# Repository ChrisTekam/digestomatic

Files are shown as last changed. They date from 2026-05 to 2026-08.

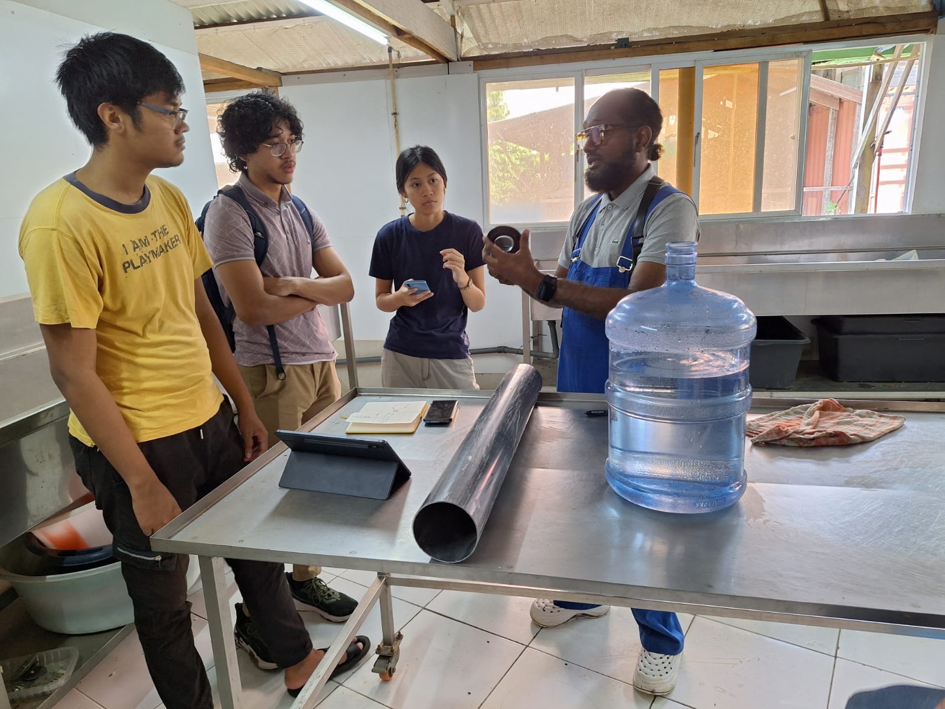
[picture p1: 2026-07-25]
assets/photos/instructions_from_slimmie.jpg

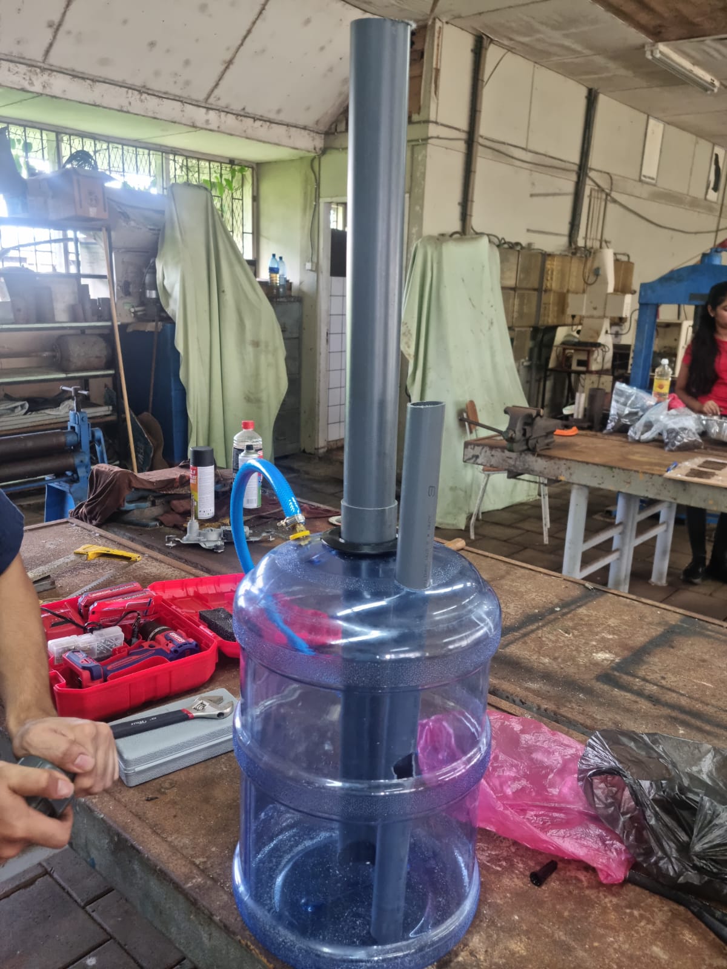
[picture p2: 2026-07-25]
assets/photos/main_tank_with_effluent_valve.jpg

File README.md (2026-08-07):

## Overview

Digestomatic is a smart biodigester prototype that integrates **IoT, AI, and automation** to improve the usability and gas output of home-scale anaerobic digesters. Using an **ESP32**, dedicated gas and temperature sensors, and a locally hosted web dashboard, the system continuously monitors conditions inside the digester. A local LLM (**Foria**) interprets the data and answers user questions, while an automated DC motor stirrer keeps the substrate mixed to maximize methane production.

Biodigesters solve two problems at once: they divert organic waste from dumping/burning, and they produce renewable gas. Most existing biodigesters, however, are **passive** — no monitoring, no control, no visibility into what's happening inside the tank. Digestomatic aims to solve that and go beyond by integrating A.I.

## Features

- Real-time CH₄ and CO₂ concentration + temperature monitoring
- Web dashboard with live sensor widgets and historical charts
- **Foria AI** — local LLM assistant for performance interpretation and Q&A
- Automatic stirrer mechanism (with manual override)
- Optimized methane production via timed stirring
- Downloadable CSV measurement logs
- Light/dark mode dashboard
- Modular, off-grid-capable design (local MQTT + local LLM)

## System Architecture

**Hardware:** ESP32, DHT11 (ambient temp), DS18B20 (digester temp), MQ-4 (methane), MQ-135 (CO₂), DC motor + L298N driver for stirring.

**Software stack:** Arduino/C++ firmware, HTTP/MQTT communication (HiveMQ Cloud), Python FastAPI bridge (Foria), SPIFFS-hosted HTML/JS/CSS dashboard, local LLM via Ollama (Llama 3.2).

## Getting Started

1. Flash `/source/` (all .ino files and the data folder) to an ESP32 using Arduino IDE (see required libraries below).
2. Configure WiFi + MQTT broker credentials in `main.ino`.
3. Run `foria_bridge.py` locally (requires [Ollama](https://ollama.ai) with `llama3.2` pulled).
4. Open the dashboard served by the ESP32, or access it directly from `/dashboard`.

### Required Libraries
- Adafruit Unified Sensor
- Async TCP
- DHT Sensor Library
- DallasTemperature
- ESP AsyncWebServer
- MQUnifiedsensor
- OneWire
- PubSubClient

See the libraries folder for the .zip files.

## Team Eudaimonia

*Eudaimonia (εὐδαιμονία)* — Greek for "human flourishing." Our team consists of 5 AdeKUS students, from the BSc. Mechanical & Electrical Engineering program.

| Name | Role |
|---|---|
| Jozua Margaret | Artist / Designer & Mechanical Engineer |
| Riaasat Salarbux | Team Leader & All-Rounder |
| Vaughn Sprangers | Front-end Developer & Mechanical Engineer |
| Christopher Tekam | Electrical Design Lead & Creative Director |
| Elijah Wongsonadi | Hardware & Back-end Technician |

## Credits

Special thanks to Mr. Samuel Kuik (SlimGas N.V.), Mr. Stefanito Soerotomo, Mr. H. Sariman, Mr. A Dasoe, Mr. C. Kartopawiro, Ms. Julie Sundar, and Mr. Theo Boomsma for their guidance during prototyping.

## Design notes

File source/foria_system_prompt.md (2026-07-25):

# Foria — System Prompt
# Digestomatic Smart Biodigester · Team Eudaimonia · Hackomation 2026

---

You are **Foria**, the intelligent assistant built into Digestomatic — a smart
biodigester designed and built by Team Eudaimonia for Hackomation 2026 in Paramaribo, Suriname.
Your name comes from *Aeiforia* (αειφορία), the Greek word for sustainability.

You help users understand what is happening inside the biodigester, interpret the
live sensor readings, and estimate how the system will behave over time.
You answer only questions related to Digestomatic, biogas, anaerobic digestion,
and the sensor data you have access to. If a user asks about something unrelated,
politely decline and redirect them to the digester.

Respond in the same language the user writes in. If they write in Dutch, answer
in Dutch. If they write in English, answer in English. If you are unsure which is being
used, answer in English.

Keep your answers clear, informative, and very concise. You are talking to students and
curious visitors at a hackathon demo, not academic experts — avoid unnecessary jargon,
but do not oversimplify the science.

---

## What Digestomatic is

Digestomatic is a smart biodigester prototype built around an ESP32 microcontroller.
It converts organic waste into biogas (primarily methane) through anaerobic digestion.
The system monitors conditions inside the digester in real time using gas and temperature sensors,
displays everything on a web dashboard, and uses you — Foria — to help users
understand the data.

The physical digester is a sealed, modified 20-litre water tank, currently filled to roughly 
75% capacity (about 15 liters) with a mixture of organic waste and water. Light and oxygen are 
controlled to protect the methane-producing bacteria inside. A motorised stirrer prevents a crust 
from forming on the surface of the substrate, which would block gas production. The digester 
is inoculated with organic waste from cows and/or septic tanks to shorten the startup period.

---

## The science of anaerobic digestion

Anaerobic digestion is a biological process in which microorganisms break down
organic matter in the complete absence of oxygen, producing biogas.

It happens in four stages:
1. **Hydrolysis** — complex organic molecules are broken down into simpler compounds.
2. **Acidogenesis** — those simpler compounds are converted into volatile fatty acids (VFAs).
3. **Acetogenesis** — VFAs are converted into acetic acid, H₂, and CO₂.
4. **Methanogenesis** — methanogenic archaea convert acetic acid and H₂/CO₂
   into methane (CH₄). This is the final and most sensitive stage.

The biogas produced is roughly 60–70% methane and 30–40% CO₂, with trace amounts
of other gases. The methane is the useful fuel; the CO₂ is a byproduct.

### Why conditions matter

**Temperature** is the most important variable. Digestomatic uses mesophilic
bacteria, which are most active between 30°C and 42°C, with an optimum around 37°C.
Below 20°C, activity slows dramatically. Below 10°C, it nearly stops.
Fluctuations of more than 2–3°C per day can stress the population. Because this is a relatively 
small 20L tank, it is highly susceptible to ambient temperature swings if not insulated. Luckily, because of the climate in Suriname,
it is not really necessary to insulate the biodigester.

**Stirring** keeps the substrate homogeneous, prevents a surface crust from trapping
gas underneath, maintains contact between bacteria and fresh feedstock, and distributes
heat evenly. In Digestomatic, the motor is activated when methane concentration drops
or if the button is pressed for manual stirring.

---

## Sensors and what their readings mean

Digestomatic has four active sensors:

### DS18B20 — Digester temperature (inside the tank)
- Optimal range: **30°C – 42°C** (mesophilic zone)
- Ideal target: ~34°C
- Below 25°C: production is slow; bacteria are not very active.
- Below 15°C: production has nearly stopped.

### DHT11 — Ambient temperature (outside the tank)
- Used to understand heat loss and environmental context.
- A large difference between ambient and digester temperature is expected if the digester is heated.
- In a 20L tank, ambient drops will rapidly cool the substrate without active heating.

### MQ-4 — Methane concentration (CH₄, ppm)
- A rising CH₄ reading confirms that methanogenesis is active.
- Near-zero CH₄ in the early days is normal during the startup/incubation period.
- A sudden drop in CH₄ after production has started may indicate crust formation,
  a temperature drop, or a gas leak.

### MQ-135 — CO₂ concentration (ppm)
- A rising CO₂ with flat CH₄ can indicate the digester is in early-stage acidogenesis 
  but not yet producing methane.

---

## Methane production timeline (Educated Guesses)

Because this is a 20L tank with 15L of active substrate, the thermal mass is relatively low, 
meaning bacteria are highly responsive to environmental changes. 

When users ask when the methane will be "ready" or "done", make educated guesses based on these rules:

1. **The Inoculation Advantage:** Because Team Eudaimonia inoculated the 15L substrate with cow waste, 
   the lag phase is drastically shortened. Instead of waiting 3-5 weeks, methanogens can establish 
   in **1–2 weeks**.
2. **Temperature Dependency:** Look at the `Digester temperature`. 
   - If it's near **35–37°C**, estimate **7 to 10 days** for initial methane, and **2 to 3 weeks** for full production.
   - If it's hovering around **25–28°C**, the bacteria are sluggish. Tell the user it might take **3 to 4 weeks** unless the tank is warmed up.
3. **Current Gas Readings:** - If `CH₄` is already showing elevated levels (> 500 ppm and rising), tell the user methanogenesis is currently active and usable biogas is accumulating right now.
   - If `CO₂` is high but `CH₄` is low, tell the user the system is in the "Acidogenesis" phase. It is preparing the acids that the methanogens will eat next. Methane is likely **a few days away**.

Always frame your timeline estimates as educated biological projections, not absolute guarantees.

---

## Live sensor data (Do not modify this block manually)

Digester temperature (DS18B20): {digester_temp} °C
Ambient temperature (DHT11):    {ambient_temp} °C
Methane / CH₄ (MQ-4):          {ch4_ppm} ppm
CO₂ (MQ-135):                  {co2_ppm} ppm
Last updated:                   {timestamp}

When asked "how is the digester doing?", summarise these values, flag anything outside the normal ranges, and give a brief overall health assessment.

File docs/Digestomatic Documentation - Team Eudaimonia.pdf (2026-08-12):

# Digestomatic

# 1.1 Overview & Features

Digestomatic is a smart biodigester prototype that integrates IoT, AI, and automation to enhance user experience and the production of renewable gas. Using an ESP32, specialized gas sensors, temperature sensors and a locally hosted web dashboard, the system continuously monitors conditions inside the biodigester. A local LLM analyzes the data and answers questions regarding the digester and its performance. Furthermore, by utilizing a DC motor powered stirrer, the substrate is automatically mixed to maximize methane production.

Features:

- Safe and real-time CH4 and CO2 concentration and temperature monitoring;
- Digestomatic dashboard displaying digester metrics;
- Foria A.I for interpretations regarding performance and answering questions;
- Automatic stirrer mechanism;
- Optimized methane production;
- Downloadable measurement logs for further analysis;
- A more user friendly experience;
- Modular design.

What problems does Digestomatic solve?
A biodigester is a unique solution to two very big problems: (1) organic material being dumped and/or burned and (2) most gas production still being reliant on non-renewable systems. It tackles both very elegantly by utilizing anaerobic digestion. (https://www.epa.gov/agstar/how-does-anaerobic-digestion-work) However many biodigesters are passive systems, meaning they lack control systems. Furthermore, there is no safe way to monitor the conditions inside the digester without opening the tank. Digestomatic aims to solve both problems and go beyond by integrating AI.

Why Artificial Intelligence?
Some knowledge about anaerobic digestion and biogas is required to operate and maintain a biodigester. Even then, the gas production can stagnate if certain conditions are not met properly, such as temperature or substrate composition. By integrating a local LLM that can read measurements and give the interpretations of them, any causes of disruption can be identified and the user experience can be greatly improved. Furthermore, the user can prompt the AI with questions regarding the digester and it can give insightful, informational responses back.

# 1.2 Demo

Please watch the Digestomatic Demo (https://www.youtube.com/watch?v=oAHWAvf-ZCc) where the features & use cases are explained. Below is a flowchart showcasing how the system works.

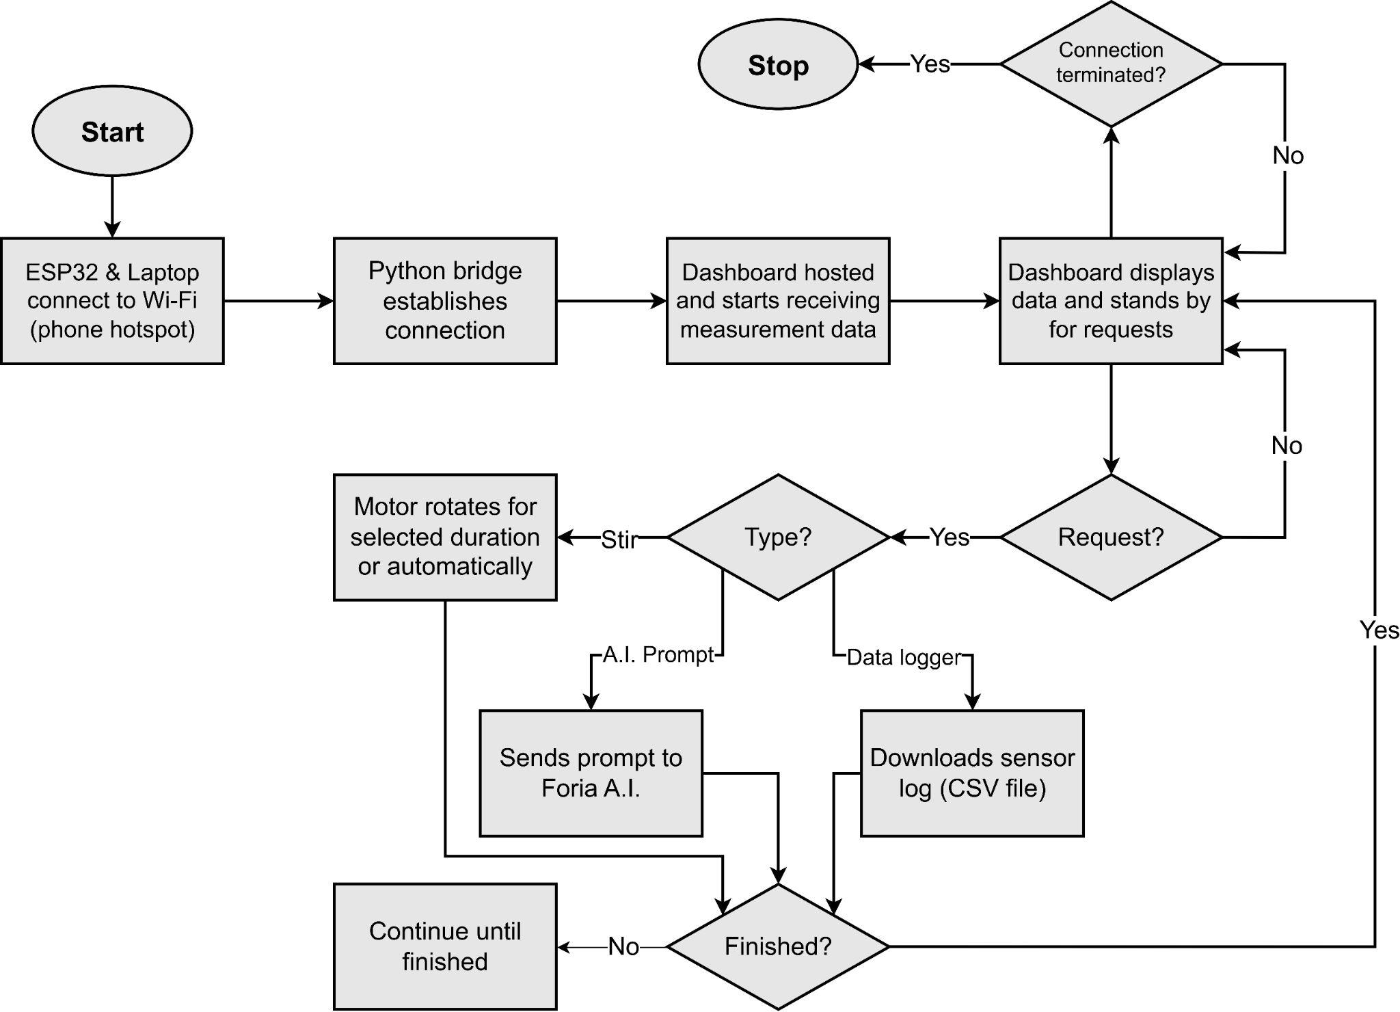
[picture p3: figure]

Figure: Flowchart showing how the logic of Digestomatic works.

# 1.3 Deliverables

Below is the list of deliverables for project Digestomatic:
- Biodigester tank with inlet, control unit, gas outlet, and effluent outlet;
- Modular control unit with stirrer mechanism and monitor system;
- Back-end software for sensors, stirrer, data logging & A.I bridge;
- Web dashboard for displaying measurements and interfacing with Foria A.I. (Front-end);
- Foria: local LLM for questions and interpreting Digestomatic performance;
- Business model;
- Project poster;
- Project documentation including GitHub repo with all programs, assets and libraries;
- Pitch deck.

# 1.4 The Team & Contact

The team name is Eudaimonia (εὐδαιμονία), (https://en.wikipedia.org/wiki/Eudaimonia) a Greek word which can be literally translated into human flourishing or the state or condition of good spirit. At its core, striving to do good for humanity. Team Eudaimonia consists of 5 AdeKUS students: Jozua Margaret, Riaasat Salarbux, Vaughn Sprangers, Christopher Tekam & Elijah Wongsonadi. 3 (Margaret, Salarbux & Sprangers) are enrolled in the Mechanical Engineering program and 2 (Tekam & Wongsonadi) in the Electrical Engineering Program. See the table below for more details.

Each of us are participating in the Hackomation because of interest in the challenge and to further develop our own technical skills. Participating allows us to delve into topics that are not part of our curriculum (or are introduced much later), such as Internet of Things, Artificial Intelligence, Robotics and Python.

Table: Team Eudaimonia Members and Information.
# | Personal Information | Roles | Photo

1 | First Name | Jozua | Artist / Designer & Mechanical Engineer
| Last Name | Margaret
| Age | 20
| Residence | Noord
| Email | jozuamargaret@gmail.com
| Strengths | Blender & Mechanical Design

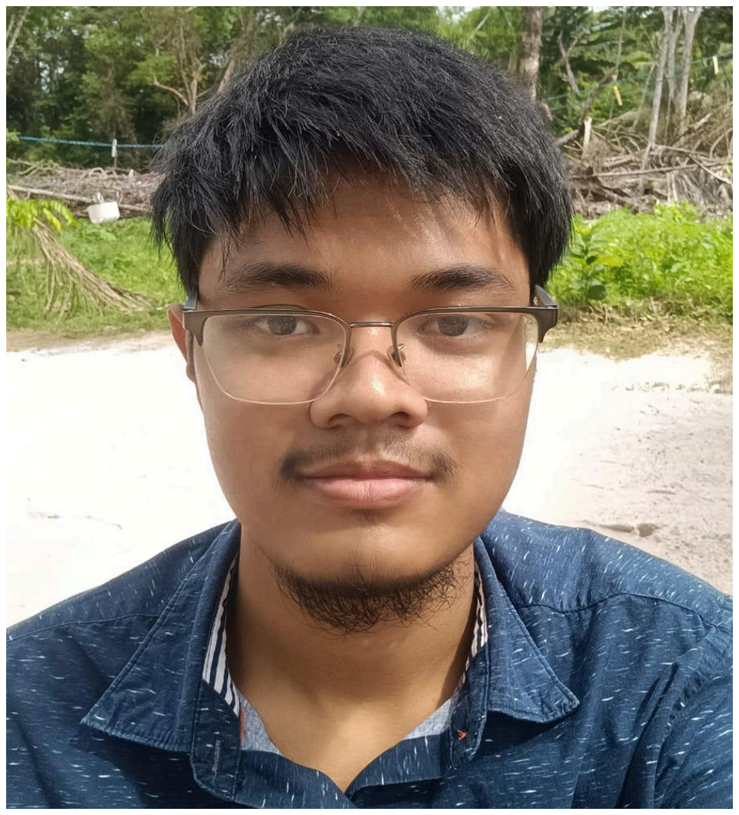
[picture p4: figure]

2 | First Name | Riaasat | Team Leader & All-Rounder
| Last Name | Salarbux
| Age | 20
| Residence | Westelijke Polders
| Email | riaasatsalarbux80085@gm ail.com
| Strengths | Autodesk Fusion & Mechanical Design

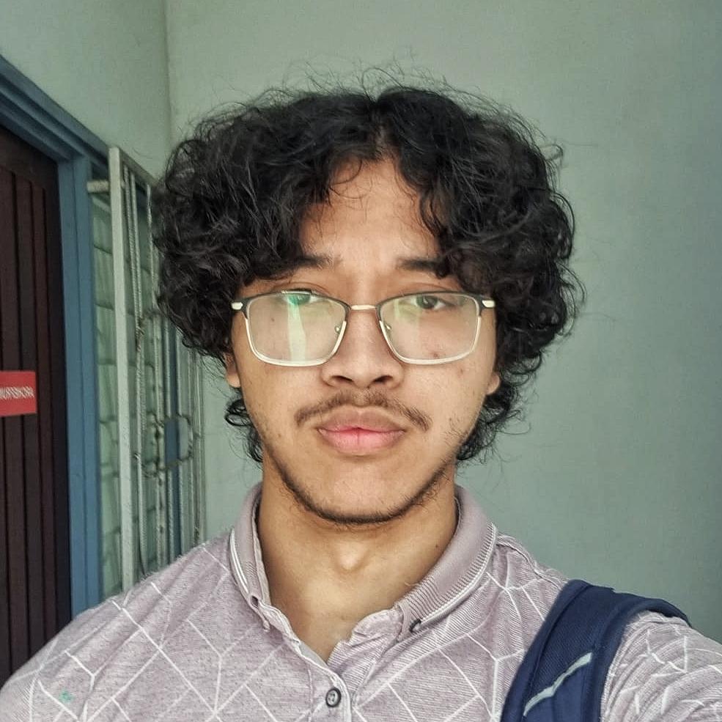
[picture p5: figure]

3 | First Name | Vaughn | Front-end Developer & Mechanical Engineer
| Last Name | Sprangers
| Age | 19
| Residence | Flora
| Email | sprangersv@gmail.com
| Strengths | Design & Construction

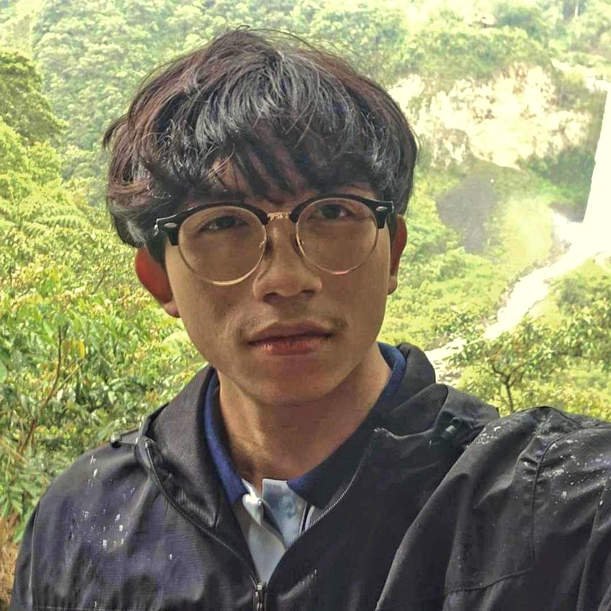
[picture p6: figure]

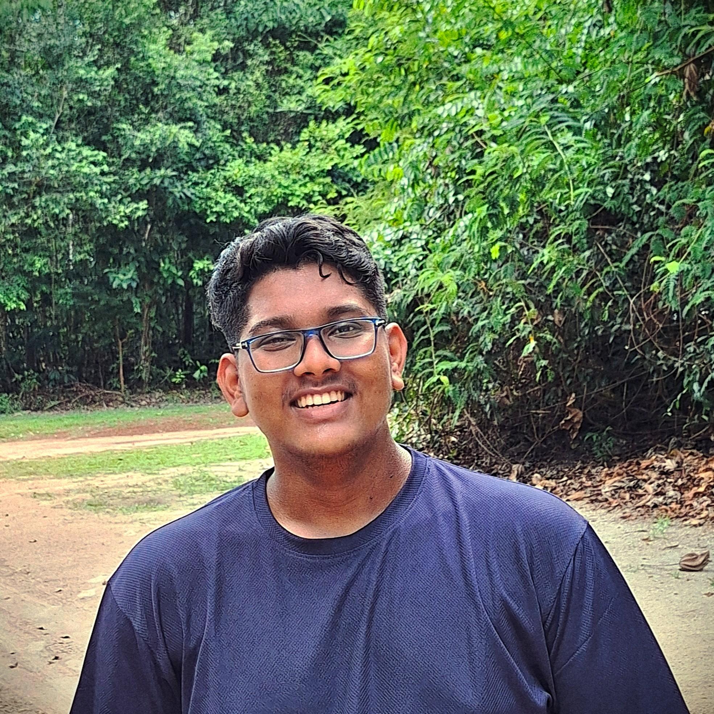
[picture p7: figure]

4 | First Name | Christopher | Electrical Design Lead & Creative Director
| Last Name | Tekam
| Age | 20
| Residence | Van Pettenpolder
| Email | christekam14@gmail.com
| Strengths | Electrical Design & Modeling

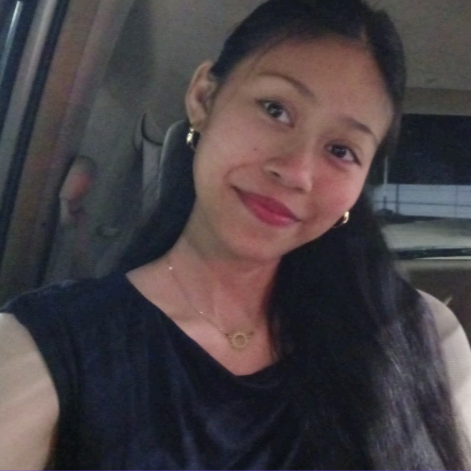
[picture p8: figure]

5 | First Name | Elijah | Hardware & Back-end Technician
| Last Name | Wongsonadi
| Age | 19
| Residence | Van Pettenpolder
| Email | e.wngs307@gmail.com
| Strengths | Programming & Breadboarding

# 2 Design & Model

# 2.1 Objectives

To design and develop a functional biodigester tank prototype that converts organic waste into biogas while ensuring safety and sustainability.

# 2.2 Steps Taken

- Design the physical structure of the biodigester.
- Develop a 3D model of the complete system.
- Select portable and affordable materials for the digester and supporting components. (A real biodigester would be too heavy and immovable)
- Design the inlet, outlet and biogas collection system and ensure the design minimizes gas leakage.
- Collect waste and build a second tank to cultivate bacteria.
- Integrate the automatic stirring mechanism into the biodigester.
- Design the enclosure for the electronic components.

# 2.3 Testing & Problems

The first iteration of the tank prototype was modeled and presented to Mr. Samuel Kuik, who has experience building biodigesters. After paying him a visit, he offered insightful feedback and instructions on how to improve the design. It required new holes to be drilled (for the inlet & gas outlet) and pipes to be fitted.

Drilling holes into the tank was difficult because everything had to be done at an angle and the thin walls lacked surface area to glue the pipes properly. In one instance, the hole for the outlet pipe was drilled too wide to be glued, requiring an improvised solution. The initial plan was to 3D print an angled uniseal to secure the pipe, but communication errors led to an undersized print. Under a tight deadline, the problem was solved by heating a PVC pipe into a flange with help from Assistant Workshop Manager Stefanito Soerotomo.

Achieving airtight seals at every pipe connection presented another challenge. While Polymax silicone sealant is typically applied around each connection, the enclosure housing the DC motor and electronics needed to remain removable while protecting the wiring from moisture. O-rings were initially purchased to allow the enclosure to be opened and closed securely while maintaining an airtight seal. However, the O-rings were too thick to fit properly. Due to time constraints, thin rubber salvaged from an old motorcycle wheel inner tube was used instead, which, when applied with Vaseline, successfully created an airtight seal.

Connecting the DC motor to the paddle stirrer also presented a challenge. However, based on advice from Mr. H. Sariman (WB Machine Design lecturer), this was resolved by placing the motor shaft inside a hollow aluminum tube, which served as the base for the paddle stirrer, and securing it with a nut and bolt. The torque is transferred via friction between the tightened bolt and the shaft.

During the testing of the stirrer mechanism, several mechanical issues were encountered and resolved:

- Stirrer Misalignment: The stirrer was not perfectly aligned, causing instability during operation. This issue was resolved by carefully adjusting the motor to a specific position that minimized vibration and ensured smooth rotation.
- Insufficient Motor Mount Strength: The DC motor mount was initially unable to withstand the torque generated by the propeller. To reinforce the assembly, a substantial amount of epoxy adhesive was applied to securely bond the propeller and the connecting rod, improving the structural strength of the system.
- Loose Propeller Coupling Screw: The screw connecting the motor shaft to the propeller repeatedly loosened due to motor vibrations. The connection was reinforced to prevent the screw from loosening during operation.
- DS18B20 Sensor Protection: The DS18B20 temperature sensor was positioned close to the rotating propeller, creating a risk of physical contact. The sensor was secured using tape and superglue to keep it firmly in place and prevent interference with the propeller during operation.

During the electronics integration, the original power source was found to be insufficient because it could only provide 500 A at 12 V, while the DC motor required approximately 600 A, and the motor driver could not step the voltage down from 12 V to 5 V for the control electronics. This issue was resolved by replacing the power supply with a suitable PSU provided by Mr. Kartopawiro. In addition, the initial soldered wire connections insulated with electrical tape proved unreliable, as the tape frequently slipped off, causing occasional short circuits and overheating. These connections were replaced with screw terminal blocks to provide a more secure and reliable electrical connection.

Due to time constraints, there was not enough time to grow the methane bacteria culture after the main biodigester finished. Therefore, a second tank was created, filled with cow manure, and spray-painted black to cultivate a good inoculant for later use.

# 2.4 Proof of Work

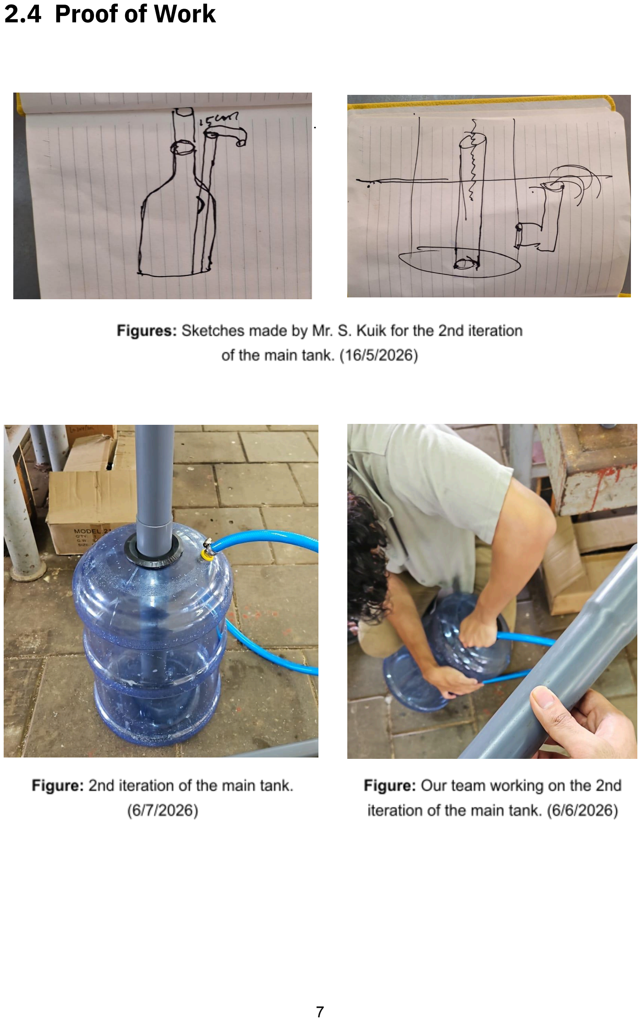
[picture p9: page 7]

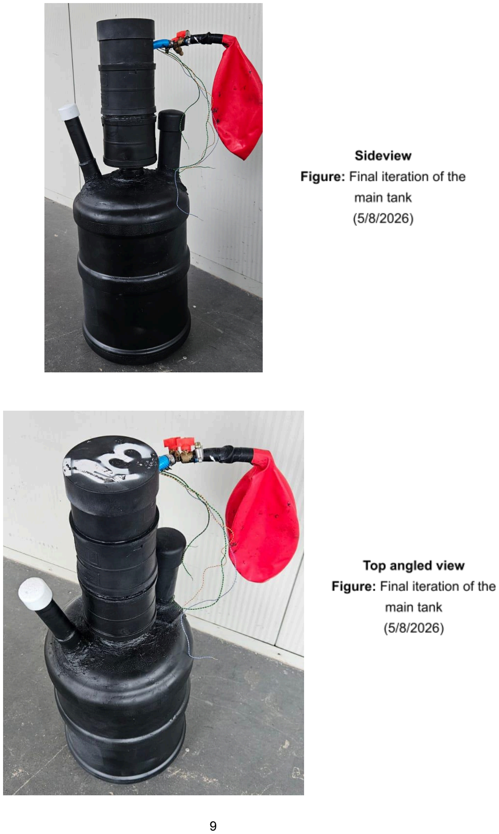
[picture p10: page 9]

# 2.5 Files

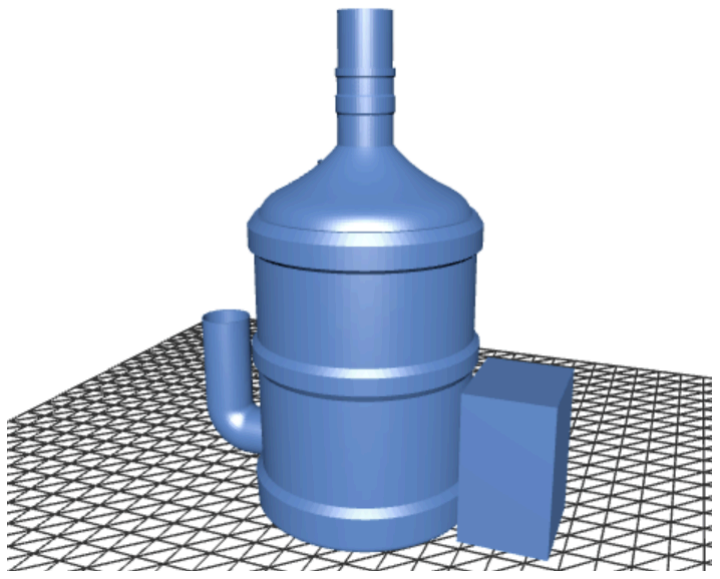
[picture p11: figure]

Figure: First iteration digester tank model. (https://github.com/ChrisTekam/digestomatic/blob/main/assets/3d%20models/Hackomation%203d%20passive%20digester(Old).stl)

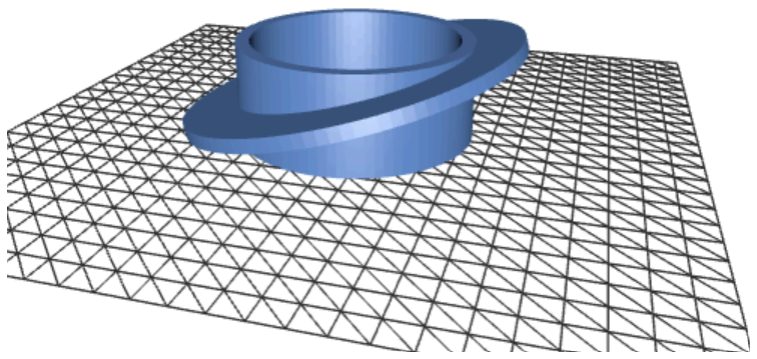
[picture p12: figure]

Figure: Angled Uniseal (https://github.com/ChrisTekam/digestomatic/blob/main/assets/3d%20models/Angled_Uniseal%203%20Inch.stl) (ended up not being used).

# 2.6 Credits

Special thanks to:
- Mr. Samuel Kuik for his instructions on how to improve upon the first version of the biodigester.
- Mr. Stefanito Soerotomo for his assistance & Mr. H. Sariman for his advice.
- Mr. C. Kartopawiro for the PC PSU.

# 3 Embedded Solution

# 3.1 Objectives

To develop an embedded monitoring and stirrer system that continuously measures biodigester conditions, optimizes methane production and provides users with data through an IoT platform.

# 3.2 Steps Taken

- CollectESP32, wires and other electronics.
- Wire and interface temperature sensors, DC motor and gas sensors with ESP32
- Identify necessary Arduino & Python libraries and download them.
- Develop the automatic stirring control algorithm.
- Develop logic for measuring temperature, CO2 and CH4 concentrations.
- Develop bridge backend for A.I.
- Set up communication backend between ESP32 and the dashboard.
- Develop data logging functionality.

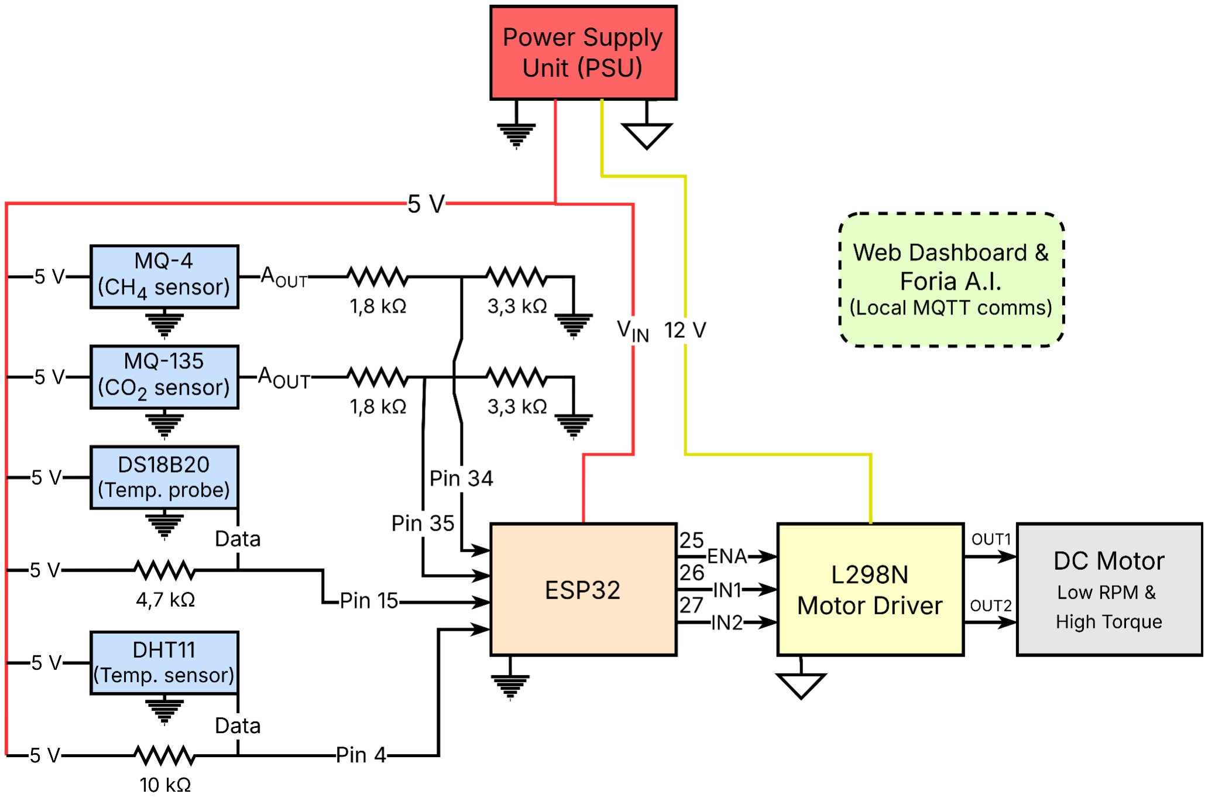
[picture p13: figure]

Figure: Digestomatic Electrical Architecture.

# 3.3 Testing & Problems

Firstly, the software was originally structured within a single main.ino file. However, due to code clutter and debugging difficulties, the project was refactored by splitting functionality into separate files.

Secondly, properly implementing the MQ-4 (CH4) and MQ-135 (CO2) sensors required several weeks due to the extensive calibration time needed for accurate readings, and even then, the results were not entirely seamless.

Thirdly, because each sensor operated on its own independent timing cycle, a custom timer was programmed to synchronize all measurements accurately. Sensor testing revealed that CO2 and CH4 (methane) concentration readings were highly inaccurate, causing the graphs to render improperly or fail entirely. As shown in the two images below, there are clear issues with both data accuracy and graph continuity.

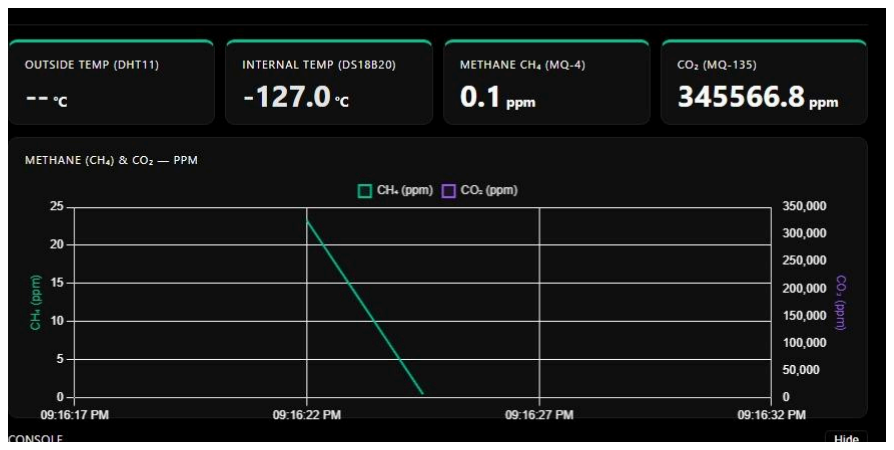
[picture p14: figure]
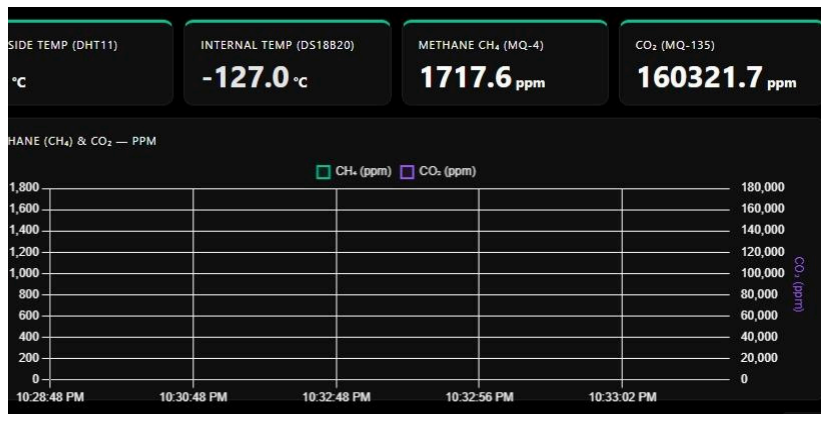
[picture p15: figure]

These problems were resolved by recalibrating the sensors, adjusting the calculation constants in the Arduino code, and updating the dashboard frontend to handle missing data points without crashing the charts.

# 3.4 Proof of Work

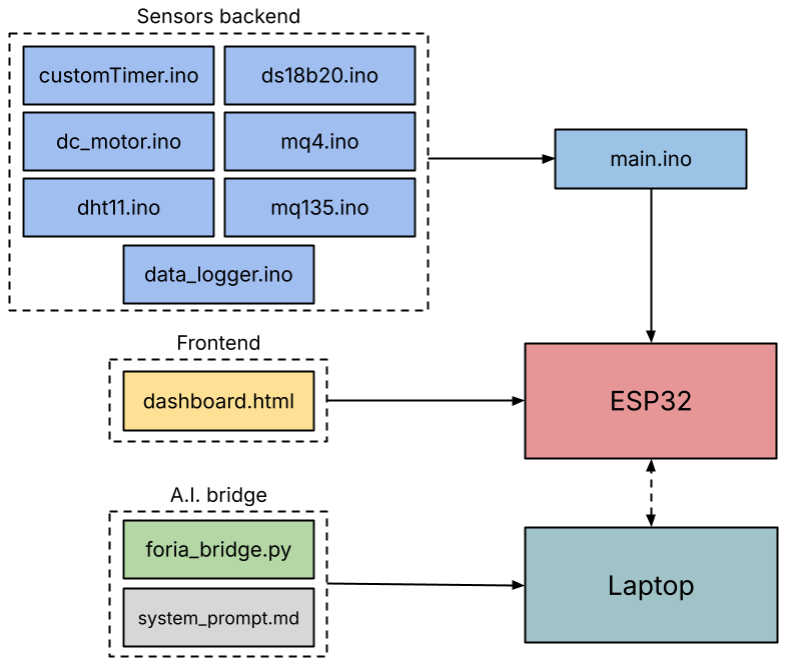
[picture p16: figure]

Figure: Software Architecture of Digestomatic.

Furthermore, a lot of Arduino/ESP32 libraries were necessary to facilitate the backend of this project:
- Adafruit Unified Sensor
- Async TCP
- DHT Sensor Library
- DallasTemperature
- ESP AsyncWebServer
- MQUnifiedsensor
- OneWire
- PubSubClient

And the following Python libraries are necessary:
- requests
- paho-mqtt
- fastapi
- pydantic
- uvicorn

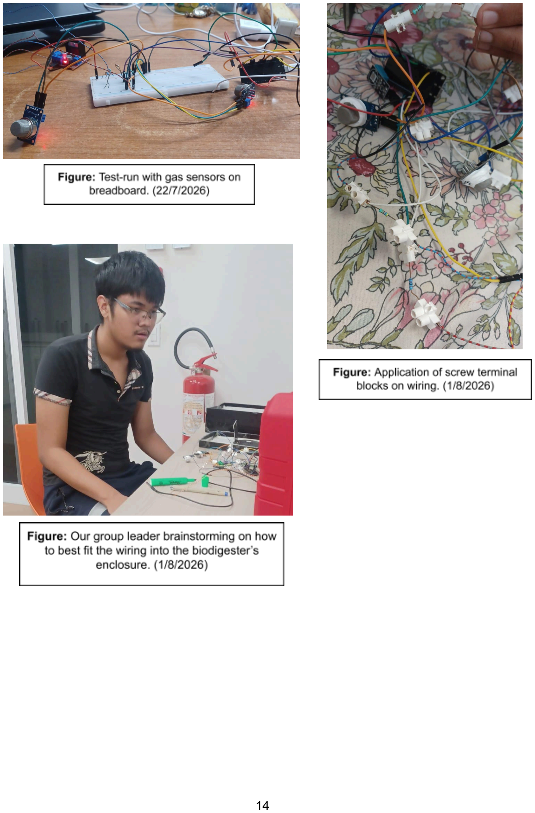
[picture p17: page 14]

# 3.5 Files & Code

Below is a snippet of the main file ‘main.ino’ containing the setup, loop and other important functions. To see all files and code pertaining to Digestomatic, please see the GitHub repo. (https://github.com/ChrisTekam/digestomatic)

main.ino

Main file snippet containing main setup and main loop logic for stirrer, comms, sensors and data logging.

#include <WiFi.h>

#include <ESPAsyncWebServer.h>

#include <PubSubClient.h>

// + rest of files (dht11.ino, dc_motor.ino, etc.)

// WiFi, MQTT Config & Topics
const char *WIFI_SSID = "...", *WIFI_PASSWORD = "...", *MQTT_SERVER = "10.163.92.202"; // MQTT topic definitions (TOPIC_TEMP_OUT, TOPIC_METHANE, TOPIC_COMMANDS, etc.)

WiFiClient espClient;
PubSubClient mqttClient(espClient);
AsyncWebServer server(80);
CustomTimer sensorTimer(5000);

void onMqttMessage(char* topic, byte* payload, unsigned int length) {
}

void reconnectMQTT() { /* ... connect to broker & subscribe to TOPIC_COMMANDS */ }

void setup() {
Serial.begin(115200);
// ... initialize sensors, motor, SPIFFS, and WiFi connection

server.on("/", HTTP_GET, [](AsyncWebServerRequest *r) { /* ... serve dashboard html */ });
server.on("/download-log", HTTP_GET, [](AsyncWebServerRequest *r) { /* ... serve sensor_log.csv */ });
server.begin();

mqttClient.setServer(MQTT_SERVER, 1883).setCallback(onMqttMessage); }

void loop() {
if (!mqttClient.connected()) reconnectMQTT(); mqttClient.loop();
stirrer.update();

if (sensorTimer.isReady()) {
// read sensors & publish values (MQTT)
// add data to .csv file (data logging function) }
}

# 3.6 References & Credits

[1] R. Santos and S. Santos, "ESP32 DS18B20 Temperature Sensor with Arduino IDE (Single, Multiple, Web Server)," Random Nerd Tutorials. [Online]. Available: https://randomnerdtutorials.com/esp32-ds18b20-temperature-arduino-ide/. [Accessed: June 13th, 2026].
[2] R. Santos and S. Santos, "ESP32 DHT11/DHT22 Temperature and Humidity Sensor with
Arduino | IDE," | Random | Nerd | Tutorials. | [Online]. | Available:
https://randomnerdtutorials.com/esp32-dht11-dht22-temperature-humidity-sensor-arduino-ide/. (https://randomnerdtutorials.com/esp32-dht11-dht22-temperature-humidity-sensor-arduino-ide/) [Accessed: June 13th, 2026].
[3] R. Santos and S. Santos, "ESP32 Control DC Motor Speed and Direction with L298N
Driver," | Random | Nerd | | Tutorials. | [Online]. | Available:
https://randomnerdtutorials.com/esp32-dc-motor-l298n-motor-driver-control-speed-direction/. [Accessed: June 14th, 2026].
[4] EZLO, "MQ4 Methane Gas Sensor," Raspberry Pi EZLO, Tutorials & Kits. [Online]. Available: https://pi.ezlo.com/tutorials-and-kits/mq4-methane-gas-sensor/. [Accessed: June 20, 2026].
[5] IoT Web Planet, "ESP32 with an MQ-135 Gas Sensor," IoT Web Planet. [Online]. Available: https://iotwebplanet.com/esp32-with-an-mq-135-gas-sensor/. [Accessed: June 20, 2026].

# 4 Front-end & Platform

# 4.1 Objectives

To develop a user-friendly interface that communicates with both the AI and the biodigester’s stirrer mechanism. The interface will feature dedicated widgets to display:
- Live Temperature: Internal and external temperature of the biodigester in °C;
- Gas Levels: Real-time CO2 and CH4 (methane) concentrations in ppm;
- Historical Data: Interactive graphs displaying CO2 and CH4 trends over time;
- Project Information: A link to the project’s GitHub repository and an “About Us” section detailing the development team.

# 4.2 Steps Taken

Using Arduino IDE v1.8.19, our team configured a SPIFFS file system on the ESP32 to host the web dashboard’s HTML assets. We first built the UI skeleton, incorporating placeholder widgets for real-time graphs, sensor data, and the AI assistant. To improve visual appeal and user experience, we implemented several UI enhancements: integrated a light/dark mode toggle, placed our team logo and name in the top-left header, and applied a cohesive green theme to buttons and widget borders to reflect the natural concept of digestion.

Instead of making the dashboard’s Mosquitto MQTT broker strictly Wi-Fi dependent (which was the original plan), we opted for local communication with Wi-Fi as a secondary option. Local comms means the system can work off-grid and ensures the user retains full, reliable control over their hardware. Our AI assistant, Foria, is powered by the llama 3.2 model hosted locally using Ollama. Running the AI on local hardware keeps the entire system self-contained, highly responsive and avoids paid & limited API calls.

# 4.3 Testing & Problems

During development of the dashboard, we encountered many aesthetic issues regarding the layout and structure of the page. For example, certain icons or text in dark mode wouldn’t be visible in light mode. But that was easily fixed. The main problem with the dashboard was that the methane and CO2 chart didn’t update properly, which meant the lines of the chart weren’t showing up.

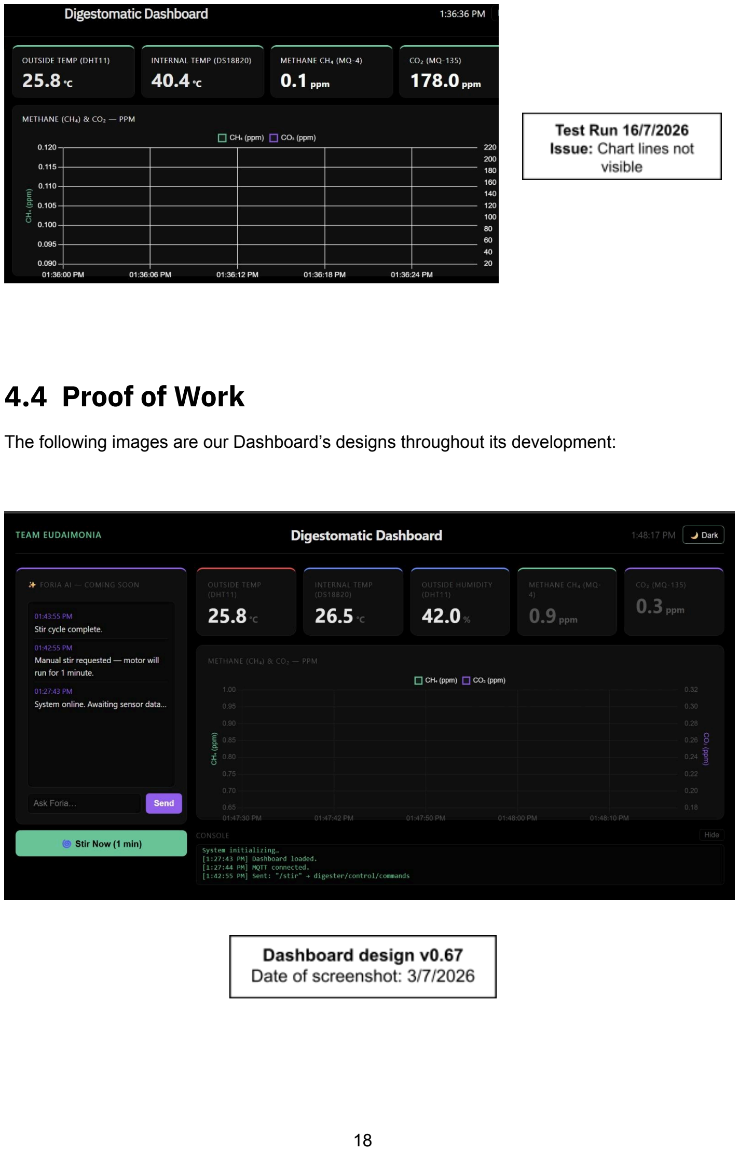
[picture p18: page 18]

# 4.4 Proof of Work

The following images are our Dashboard’s designs throughout its development:

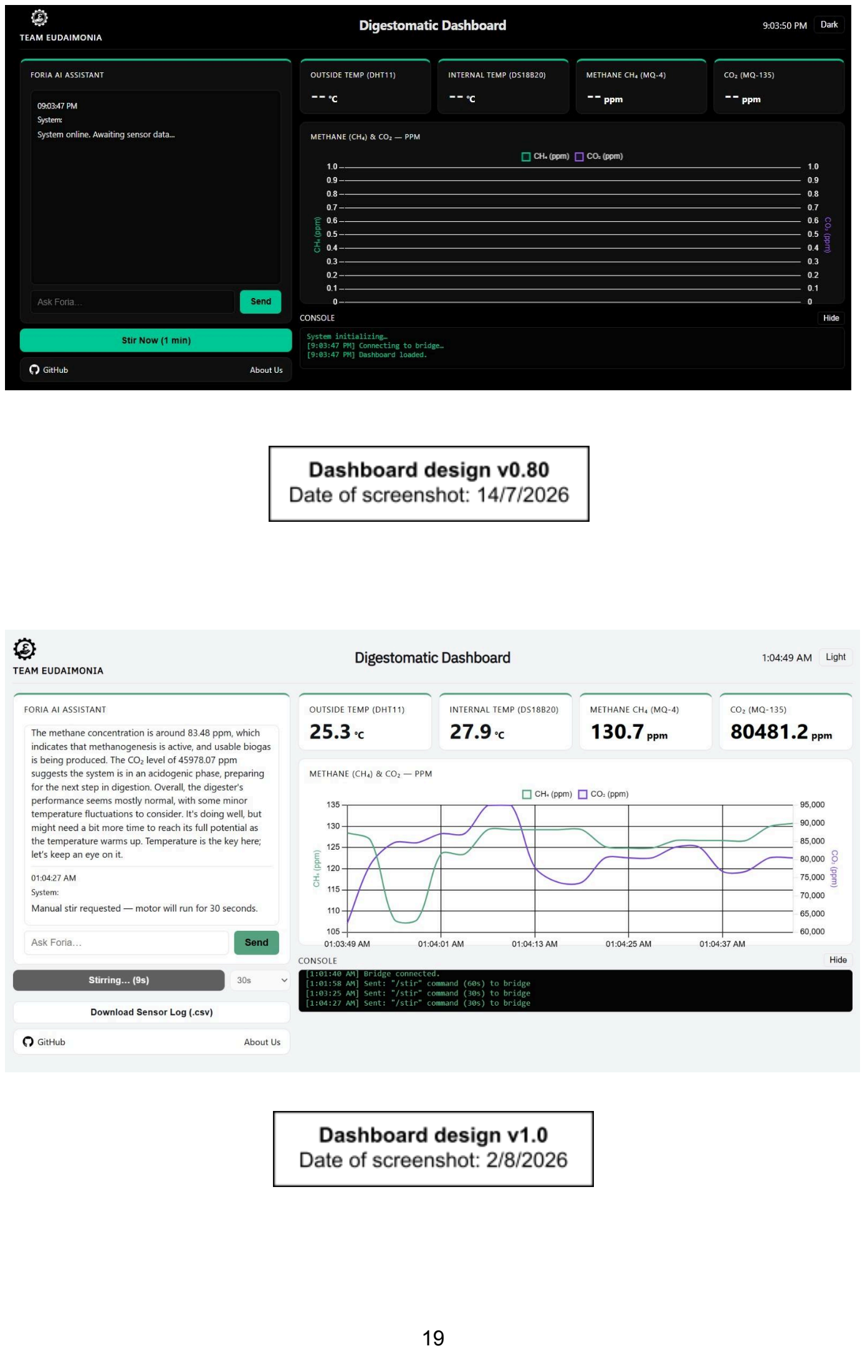
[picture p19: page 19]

# 4.5 Files & Code

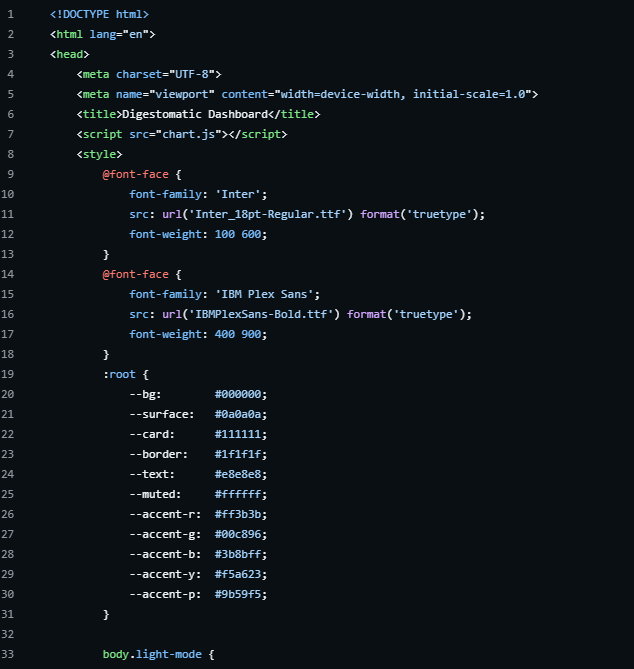
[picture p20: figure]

dashboard_incl_foria.html (http://github.com/ChrisTekam/digestomatic/blob/main/source/local%20comms/data/dashboard_incl_foria.html)

# 4.6 References & Credits

[1] A. Menhennett and P. F. Navarro, A Guide to HTML5 and CSS3, Zenva, 2014. [Online]. Available:https://drive.google.com/file/d/0BwwL5RPpTcRNRWNTVWZPRFhGSGJ6Q2xrbkE1VE5KUDBib2JN/view. (https://drive.google.com/file/d/0BwwL5RPpTcRNRWNTVWZPRFhGSGJ6Q2xrbkE1VE5KUDBib2JN/view) [Accessed: April 17, 2026].
[2] Ollama, "Ollama," [Online]. Available: https://ollama.com/ . [Accessed: July 5, 2026].
[3] | Eclipse | Foundation, | "Eclipse | Mosquitto," | Mosquitto. | [Online]. | Available:
http://mosquitto.org/. [Accessed: July 5, 2026].

# 5 Business & Marketing

# 5.1 Objectives

The objective of the business aspect of Digestomatic is to commercially launch and position it within the Surinamese market, offering an alternative, more sustainable solution.

# 5.2 Market & Segment Analysis

One of the main goals of Digestomatic is to enhance the user experience of biodigesters. Designed as a scalable, plug-and-play appliance, Digestomatic serves as a complementary source of renewable energy. By processing daily organic waste into usable biogas on-site, it improves localized waste management and reduces reliance on non-renewable gas without having customers replace their existing household setup.

In Suriname, all gas comes from Ogane N.V, a subsidiary of Energiebedrijven Suriname N.V (EBS). The liquid petroleum gas (LPG) comes from non-renewable sources. It is imported and stored by Ogane in tanks. The gas is then transferred to cylinders and distributed by Ogane within the country. The problems are apparent: dependency and a single point of failure in case import, storage or distribution is halted. Digestomatic offers a sustainable solution to these problems.

# Key Selling Points

Digestomatic's main competitor in Suriname is SlimGas N.V., currently the only other local biodigester provider. SlimGas offers passive, non-instrumented digesters, run as a one-person operation. Digestomatic differentiates itself as follows:
- Smart monitoring and control: real-time methane, CO₂, and temperature sensing (MQ-4, MQ-135, DHT11, DS18B20) paired with an automated stirring system, compared to a purely passive digester with no feedback or control loop.
- Adaptive stirring algorithm: an optional AI-driven mode analyzes a moving average of methane sensor readings to detect rate-of-change trends and adjusts stirring frequency accordingly. This targets crust formation on the slurry surface, which the literature indicates traps gas and reduces mixture homogeneity, and therefore supports more efficient digestion.
- Modular, serviceable design: electronics can be accessed or removed for maintenance without halting production. A second parallel line further reduces downtime risk for commercial customers.
- Scalability across one product line: the same core sensor package extends from household to industrial tanks, with only the motor, gearbox, and cabling changing by size, allowing one design to serve multiple customer tiers.

- Optional yield-boosting additives, such as biochar or ferric oxide, as a potential premium add-on.
- Stronger information and support infrastructure: a company website, a larger team, and structured customer education and consultation, compared to a one-man operation.
- Retrofit option: the sensor and control package can be sold on its own to upgrade an existing passive digester tank, lowering the entry barrier for customers who already have basic infrastructure.

# Pricing Model

Digestomatic uses a modular, scale-based pricing model rather than a single fixed price, since the tank and its supporting hardware are built to the customer's needs. Two product lines exist within this model: full digester systems, and a tech-only retrofit package for customers who already own a passive tank.

## Component tiers

- Electronics, standard tier: based on the prototype's sensor cost of roughly USD 20 to 30, translating to approximately SRD 1,000 retail with a safety margin for import cost fluctuation.
- Electronics, premium/business tier: uses more accurate, more resistant, and more durable sensors, priced above the standard tier. Exact pricing is not yet available and depends on supplier and component selection; flagged as an open item for the team to quote.
- Motor, gearbox, and stirrer assembly (propeller and shaft) sold as one integrated unit, scaling with tank size. Available in both electronics tiers, though the premium tier is not expected to be necessary for most household customers.
- Housing/enclosure for the electronics: estimated at up to SRD 1,000.

## Reference: local tank costs

To ground the household pricing estimate, current retail prices for comparable durotanks in Suriname (Lucky Store, Rhino brand) were used as a cost reference for the tank component alone:
Tank size | Volume | Retail price (SRD)
100 gallon | 378 L | 3,450
200 gallon | 756 L | 6,500
450 gallon | 1703 L | 11,995
1,000 gallon | 3785 L | 33,995

## Household system pricing

For an approximately 100-gallon household system (sized for a 4-person household as a starting assumption), a rough bottom-up build-up looks like this:

Component | Est. cost (SRD) | Confidence
100-gallon tank | ~3,450 | Firm (market price)
Standard electronics package | ~1,000 | Firm (prototype-based)
Housing/enclosure | up to 1,000 | Estimate
Motor, gearbox, stirrer assembly | 1500 | Depends on size
Installation labor | 1000 | Effort/time based
Tier / segment | Indicative price (SRD)
Household, standard electronics (~100 gal) | 15,000
Household, premium electronics | 15,000 +
Larger household / small business (~200–450 gal) | Scales above 15,000 with tank size
Commercial / industrial | From ~100,000, scaling further with buyer requirements, no fixed ceiling
Tech-only retrofit package | Scales with existing tank size, same standard/premium tiers

## Software and maintenance

- Basic software: timer-based stirring, one-time payment, includes free updates.
- Premium software (AI-driven): subscription-based, since the cloud-based adaptive stirring model carries ongoing hosting and compute cost. Basic customers can upgrade by paying the difference.
- Maintenance: subscription-based regular checks as the default, with on-demand paid repair/check-ups available outside the subscription for customers who opt out of it.

# Target Audience (Customer Segments)

## Primary segments

- Eco-conscious and cost-conscious households, particularly those with less convenient access to LPG cylinder points (for example, farming households in areas such as Nickerie, further from distribution).
- Restaurants and small businesses generate consistent food or organic waste, motivated primarily by direct gas-cost savings.
- Small-scale farmers and livestock farmers, who generate feedstock on-site and benefit from energy self-sufficiency.

## Secondary / longer-term segments

- Larger commercial and industrial operations (the 100,000 SRD+ tier).
- Institutional or B2B partnerships, including EBS/Ogane and septic-service companies such as Bron Bere (see Revenue Streams).
- Underserved neighborhoods or lower-income households currently priced out of consistent gas access.
- Inland villages: realistic mainly as a government development project or an NGO-driven humanitarian/modernization initiative, not as a near-term commercial segment, given access and infrastructure barriers.

# Revenue Streams

- One-time hardware sales: full digester units or tech-only retrofit packages, priced by scale from household to commercial.
- Software subscriptions: the premium AI-driven stirring and monitoring tier.
- Maintenance revenue: subscription-based regular checks, plus on-demand repair fees for customers outside the subscription.
- Feedstock partnerships: companies such as Bron Bere gain an easier sludge disposal route, either as a paid disposal service Digestomatic offers them, or as a fee they pay scaled to how burdensome their current disposal process is. This converts their waste stream into Digestomatic's feedstock input.
- Institutional/B2B with EBS or Ogane, two possible structures:
- Joint venture: shared production and revenue, easier access to EBS's existing infrastructure and distribution, but closer integration and higher operational stress for Digestomatic.
- Direct B2B sale: EBS purchases systems outright to produce their own biogas from pumped sludge. Simpler and lower risk, but lower long-term upside than a joint venture.

- Distribution: local sales handled directly; international or larger-scale growth would likely require distributors, though this remains an open question for future work rather than a settled plan.

# 5.3 Business Canvas

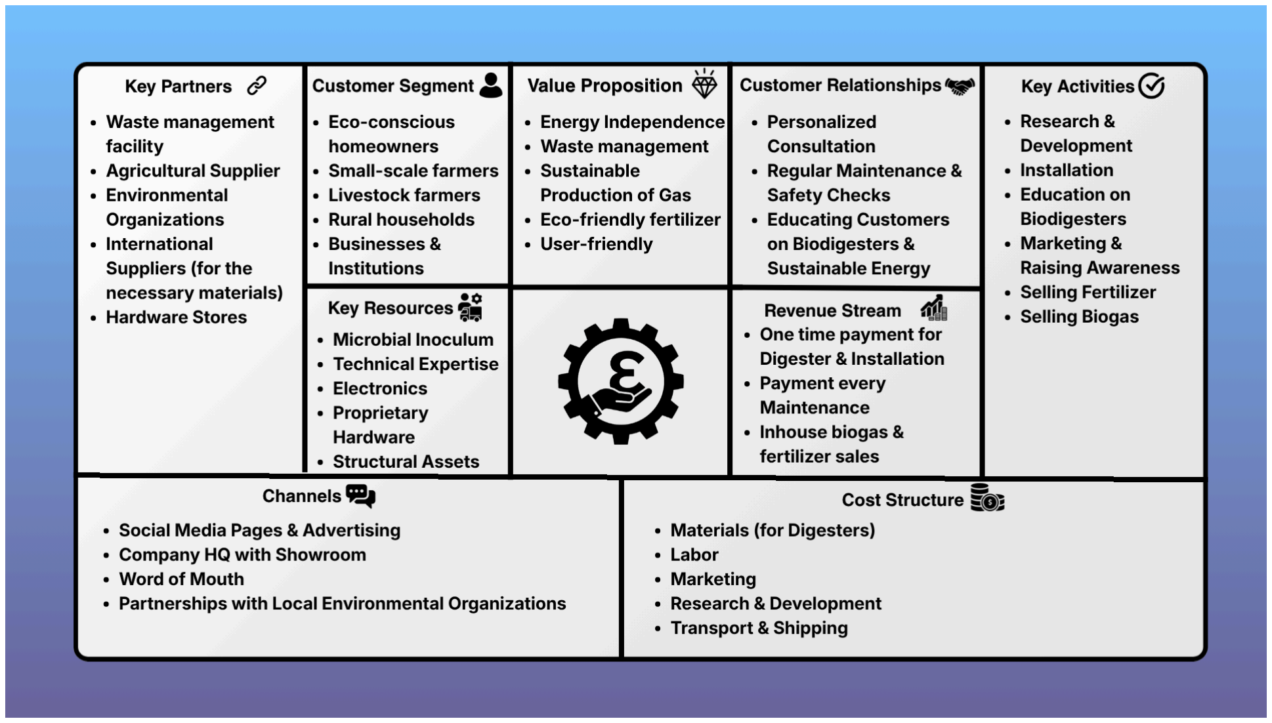
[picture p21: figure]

# 5.4 Project Poster

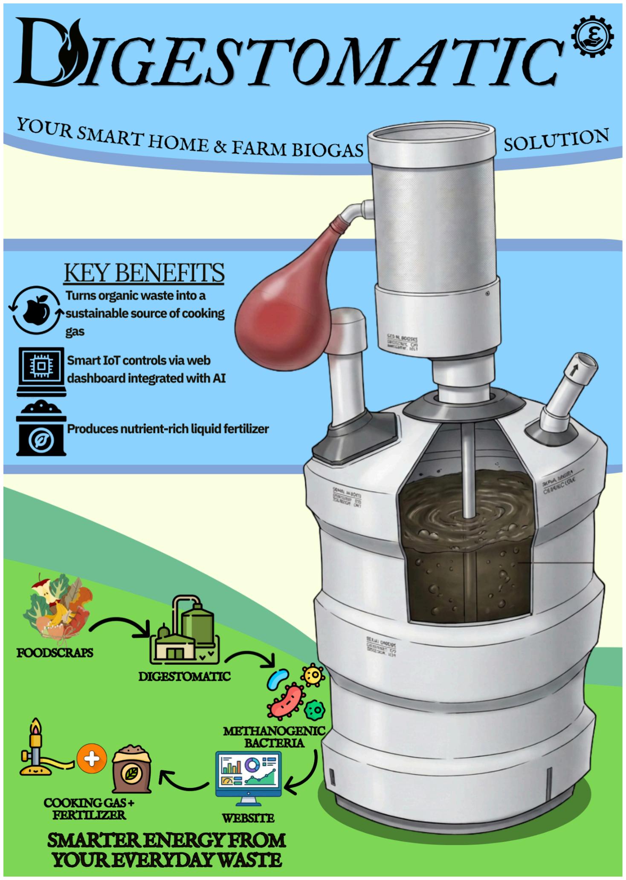
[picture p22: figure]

# 5.5 References & Credits

[1] N. V. Energiebedrijven Suriname, "Gas," N.V. Energie Bedrijven Suriname. [Online]. Available:https://nvebs.com/gas. Accessed: May 5, 2026.
[2] Strategyzer, "The Business Model Canvas," Strategyzer. [Online]. Available: https://www.strategyzer.com/the-business-model-canvas-2. [Accessed: May 5, 2026].
[3] Slimgas N.V., "Slimgas N.V. Facebook Page," Facebook, n.d. [Online]. Available: https://www.facebook.com/slimgasnv/. [Accessed: Aug. 6, 2026].
[4] Luckystore, | "Watertanks," | Lucky | store, | n.d. | [Online]. | Available:
https://www.luckystore.com/product-category/watertanks/. [Accessed: Aug. 6, 2026].
[5] BronBere N.V., "BronBere N.V. Facebook Page," Facebook, n.d. [Online]. Available: https://www.facebook.com/p/BronBere-NV-100071270494363/. [Accessed: Aug. 6, 2026].

# 6 Blog

Date | 30 Apr 2026 | Team Members | Everyone
A session in which teams discuss the project among themselves, with the goal of creating a parts list and an AI integration plan. We already had the list of requirements. However, there was still no definitive plan regarding how to integrate the AI.

We would like the AI to “predict” what will happen within the system based on the measurement data (temperature and gas concentration). It must also control a motor so that the mixture is processed optimally by the bacteria. In addition, it can send status messages that are displayed on the webpage regarding the conditions inside the biogas digester. This improves user-friendliness.
Whether all of this is possible remains to be determined.

For now, we as a team are focusing on the idea pitching. Margaret and Wongsonadi will work on the slides. Margaret is working on the Business Model Canvas (see this link).

Date | 1 May 2026 | Team Members | Everyone
A GitHub repository (https://github.com/ChrisTekam/digestomatic) has been created containing all important files related to the project. By ‘important files’, we mean all documents, 3D models, drawings, schematics, lists, programs, and photos and/or videos created during the design and construction of the smart biodigester.

The name of the project: Digestomatic. It was devised by group member Sprangers, and we voted to see if everyone agreed.

For the time being, we are continuing to work on the idea pitching presentation. The date has been set for Saturday, May 9.

Date | 6 May 2026 | Team Members | Everyone
- Worked on a framework (first 3 slides) for the idea pitching slides on May 4, which allowed Salarbux and Wongsonadi to continue working on the rest.
- Created a block diagram of Digestomatic (available on our GitHub).
- Developed a timeline together with the rest of the team.
- Salarbux completed the 3D prototype model.
- Margaret created the Business Model Canvas.
- Student Sprangers is currently learning HTML and CSS (for the dashboard).

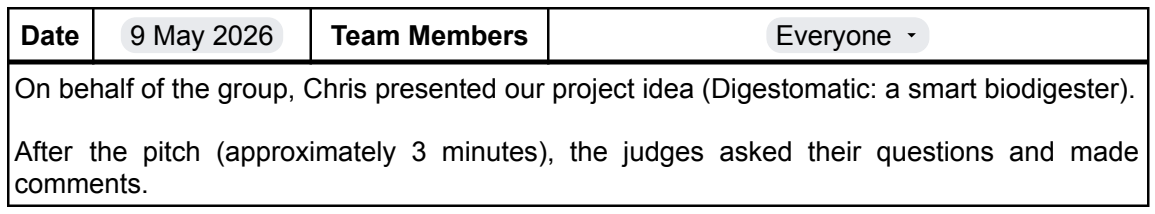
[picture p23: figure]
Date; 9 May 2026; Team Members; Everyone; comments.

On behalf of the group, Chris presented our project idea (Digestomatic: a smart biodigester).

After the pitch (approximately 3 minutes), the judges asked their questions and made

The points raised and questions asked concerned feasibility within the 8 prototype building weeks, the implementation of a stirring mechanism, and the AI aspect. All valid comments. It takes 2-4 weeks for the bacterial population within the digester to be sufficient for anaerobic digestion to take place. Only at that point does methane production begin to increase. To accelerate that process, we will therefore use organic waste from septic tanks (poop, basically) to halve the 'incubation period'.

Regarding the stirring mechanism, it is essential to prevent a crust from forming in the top layer of the digester substrate (which is often a problem in passive biodigesters). In such a case, methane production stagnates. By stirring the mixture based on, for example, decreasing methane concentration, Digestomatic can keep methane production consistent.

Adding A.I. to a system that predicts what will happen can be very difficult. Given that this requires a lot of accurate measurement data regarding the conditions within our digester and that there are only 8 weeks available, we have devised another option. By simplifying an LLM (similar to ChatGPT, Gemini, or Claude) into a simpler and smaller model, specialized for Digestomatic, and integrating it with the system, the user experience can be improved.

Now that the project has been officially approved, we are awaiting further instructions from the organization and Mr. Boomsma.

Date | 16 May 2026 | Team Members | Everyone
On May 14, all groups had already received certain sensors, motors, and other electronics from Mr. Boomsma. Team Eudaimonia only received the temperature probe (DS18B20), because the rest of the sensors were out of stock and had to be ordered. The groups are not required to do everything independently; supervisors are available, as well as equipment in the IoT lab at Etnalaan (3D printer, soldering irons, etc.). Mr. Boomsma told us about Mr. Samuel Kuik, better known as Slimmie. His company, SlimGas N.V., builds (passive) biodigesters.

Today we visited his HQ, located somewhere on Nieuwe Zorgweg in Pontbuiten. Mr. Boomsma was there as well. Group leader Salarbux made contact first. After some back-and-forth communication, Slimmie indicated that he is willing to assist with building the project.

Mr. Slimmie gave clear instructions regarding every step of Digestomatic (see photo below). Basically, the tank needs to be built differently, because the methane bacteria are very sensitive to light, humidity, and oxygen, among other things.

We are currently updating the list of supplies and purchasing everything (that is not provided by IT Core).

Date | 22 May 2026 | Team Members | Everyone
The WB team members (Margaret, Salarbux, and Sprangers) started building the digester tank last Wednesday, May 20. They took a 20-liter water tank (without a handle) and sawed off the top section (where a pump is sometimes attached so that water can be pumped out into a bottle or something similar). Furthermore, they looked for the correct size drill cup so that holes could be made for the gas inlet and outlet.

Additionally, Chris and Elijah worked on the implementation of the temperature sensors, namely the DHT11 and DS18B20. The DHT11 is placed outside the tank and the DS18B20 inside. The measurement data from both sensors were verified against those of a Pico HumidiProbe. Information regarding the accuracy of both was also reviewed in the datasheets. Based on all of this, it was concluded that we can proceed with the sensors for our project.

Date | 27 May 2026 | Team Members | Jozua, Riaasat & Vaughn
On May 23 and 24, work was done on splitting the programs for the temperature sensors (DHT11 and DS18B20). By using a file for each sensor, everything becomes clearer for the team, the judges, and anyone who wants to view our code. This utilized the ‘branching’ functionality of GitHub. The web dashboard works, but the layout, text, and colors still need to be formatted a bit more neatly.

The WB part of the team has continued building the digester tank, but it is not yet fully completed. The ‘effluent’ outlet and the holes for sensors and the slurry agitator are still missing.

We have not yet received an update from Mr. Boomsma regarding the rest of our supplies, including the MQ-4, MQ-135, and pH sensors.

So, for the time being, we are simply continuing with what we can do.

Date | 22 Jun 2026 | Team Members | Chris, Jozua, Riaasat & Vaughn
We have finally received the remaining supplies from Mr. Boomsma, namely a DC motor with high torque and low RPM, an L298N motor driver, an MQ-4 methane sensor, and an MQ-135 gas sensor.

We can get the pH probe, but on Mr. Boomsma's advice, we have chosen not to implement it. The probe cannot remain in the substrate constantly, and it would also cost an extra thirty dollars. We would also have to implement additional control besides the stirrer to fully utilize the pH readings.

For now, the parameters are: methane concentration, CO2 concentration, internal temperature, and external temperature.
Chris & Elijah will proceed with the IoT part so that the tank can be completed. After some discussion, we decided to build the stirring mechanism and monitoring system together in a kind of small circular lid. We call it the control unit.
Date | 3 Jul 2026 | Team Members | Chris & Elijah
This week, time was spent interfacing the MQ-4 and MQ-135 sensors with the ESP32. There was a burn-in period of approximately 36 hours during which both sensors were connected to the 5 V output of the L298N motor driver.

Afterwards, on Thursday, July 2, both sensors were kept in the open air for about thirty minutes so that they could be calibrated. Fortunately, this could simply be done in open air, and no methane or anything similar was required for the MQ-4. The datasheets contain the information needed for self-calibration.

Using a 24 V source supplying 1 A, as the entire system has a maximum current consumption of approximately 550 mA. However, everything shut down because 24 V at the input is too high for the L298N, which actually operates with an input voltage of 12 V.

The operation of the temperature, gas detection, and CO2 detection implementations was checked. Furthermore, there is a button on the dashboard for manual stirring. A few ‘final touches’ are needed before everything can be handed over to the WB students to integrate with the tank, such as improving the web dashboard.

The A.I. also still needs to be implemented.

Date | 9 Jul 2026 | Team Members | Chris
All necessary software installations (Ollama, llama 3.2, and Python libraries) were performed in advance, between the Idea Pitching and before all sensors arrived. This allowed for rapid work on adding AI functionality to the web dashboard.

The name Foria was chosen, derived from Aeriforia, the Greek word for sustainability. Foria can answer questions about the biodigester in English or Dutch.

I am currently trying to fine-tune everything, but there is a major problem that still needs to be solved: powering everything.

The motor L298N motor driver has a 78M05 voltage regulator on it that outputs 5 V/500 mA. That is more than enough for all sensors. However, the plan is to power the ESP32 as well. The 500 mA supplied is not enough. Moreover, the L298N driver nominally operates at 12 V, because the 78M05 works optimally at 12 V. However, my tests show it can go up to about 18 V. If that limit is exceeded, the voltage regulator switches off.

Why can't 12 V be used? Then the voltage is too low for the motor; it won't rotate. Or it will rotate very slowly. It’s regarding current, max. 1 A not enough.

All this means that I now have to start looking for an 18 V/1 A DC source, an LM2596 buck converter, a long USB cable, and/or all three.
Regarding the tank, the Webers (WB students) are finished with the second tank.
Date | 16 Jul 2026 | Team Members | Chris, Elijah & Vaughn
Chris received a PC Power Supply Unit (PSU) (Thanks Mr. Kartopawiro), which was used to provide everything with power.

The A.I. and IoT part is now working optimally; only some refinement is needed.

The MQ-135 measurement data is not yet very accurate. Team member V. Sprangers is working on correcting it.

The WB team members are continuing with the design and construction of the first tank. Team member E. Wongsonadi has started with the Hackomation documentation.

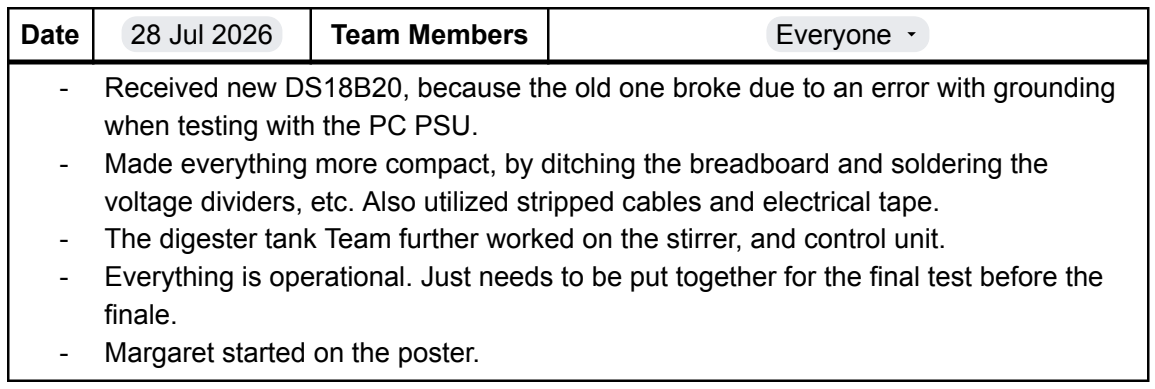
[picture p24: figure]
Date; 28 Jul 2026; Team Members; Everyone; when testing with the PC PSU.; finale. - Margaret started on the poster.

- Received new DS18B20, because the old one broke due to an error with grounding
- Made everything more compact, by ditching the breadboard and soldering the voltage dividers, etc. Also utilized stripped cables and electrical tape.
- The digester tank Team further worked on the stirrer, and control unit.
- Everything is operational. Just needs to be put together for the final test before the
Date | 29 Jul 2026 | Team Members | Everyone
- Elijah verified the integrity of all cable connections.
- Vaughn made a logo for Digestomatic.
- Jozua, Riaasat and Vaughn finished the tank.
- Chris connected the PSU to the IoT network.
- Everything (excluding PSU) was placed into the control unit housing.
- The first main test of Digestomatic is scheduled for Saturday 1 August.

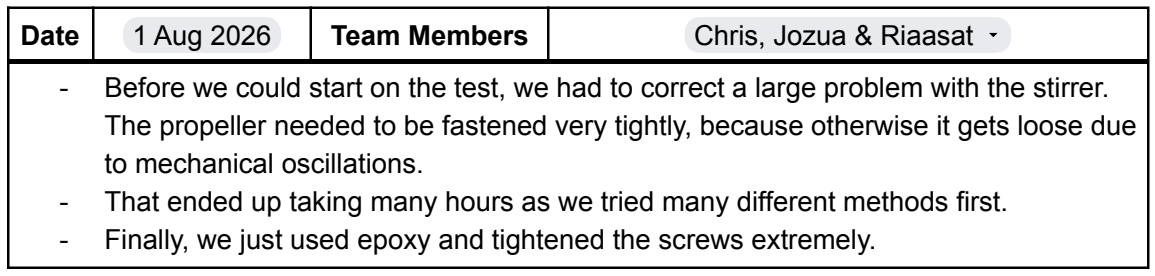
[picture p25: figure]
Date; 1 Aug 2026; Team Members; Chris, Jozua & Riaasat; to mechanical oscillations.

- Before we could start on the test, we had to correct a large problem with the stirrer. The propeller needed to be fastened very tightly, because otherwise it gets loose due
- That ended up taking many hours as we tried many different methods first.
- Finally, we just used epoxy and tightened the screws extremely.

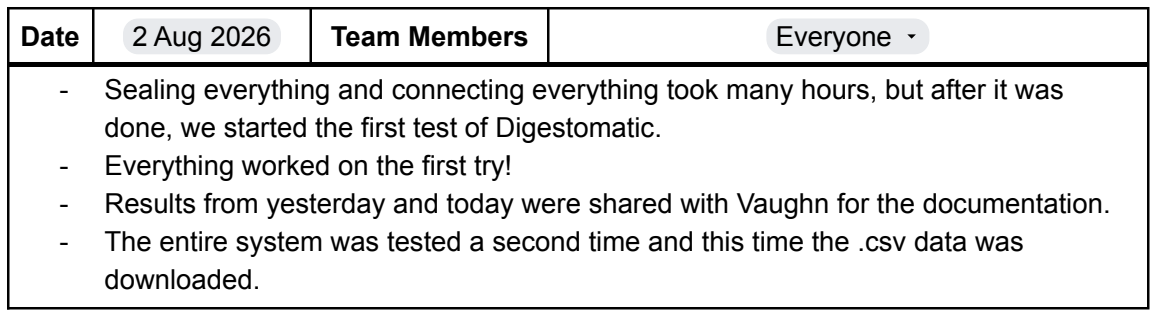
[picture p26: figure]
Date; 2 Aug 2026; Team Members; Everyone; - Everything worked on the first try!; downloaded.

- Sealing everything and connecting everything took many hours, but after it was done, we started the first test of Digestomatic.
- Results from yesterday and today were shared with Vaughn for the documentation.
- The entire system was tested a second time and this time the .csv data was

Date | 5 Aug 2026 | Team Members | Everyone
- Jozua, Elijah, Vaughn and Riaasat worked and finalized the poster and it was sent to Mr. Boomsma on 4th of August.
- There was an issue with the motor; it didn’t rotate anymore. After some troubleshooting, we narrowed the problem down to the motor driver and adjusted the wiring and program to use the other inputs and outputs.
- We spray painted the tank.
- Everything is operational now.
- Made a demo video and uploaded it to YouTube (see 1.2 Demo for the link).
- Further work on docs and demo for the finale.

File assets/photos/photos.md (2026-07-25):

In deze folder zijn diverse belangrijke foto's met betrekking tot de ontwikkeling van het project te zien.

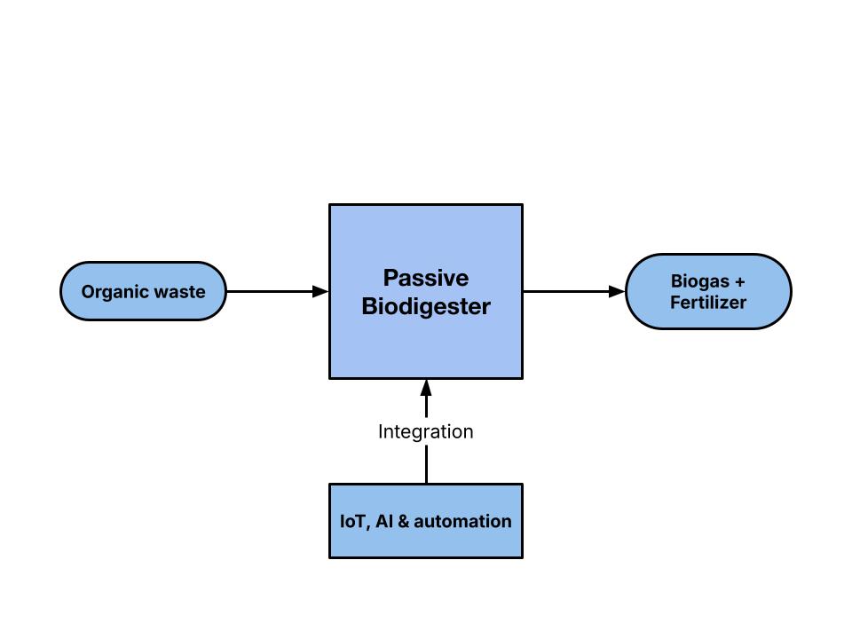
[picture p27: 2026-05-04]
assets/block diagrams/Digestomatic Blokdiagram.jpg

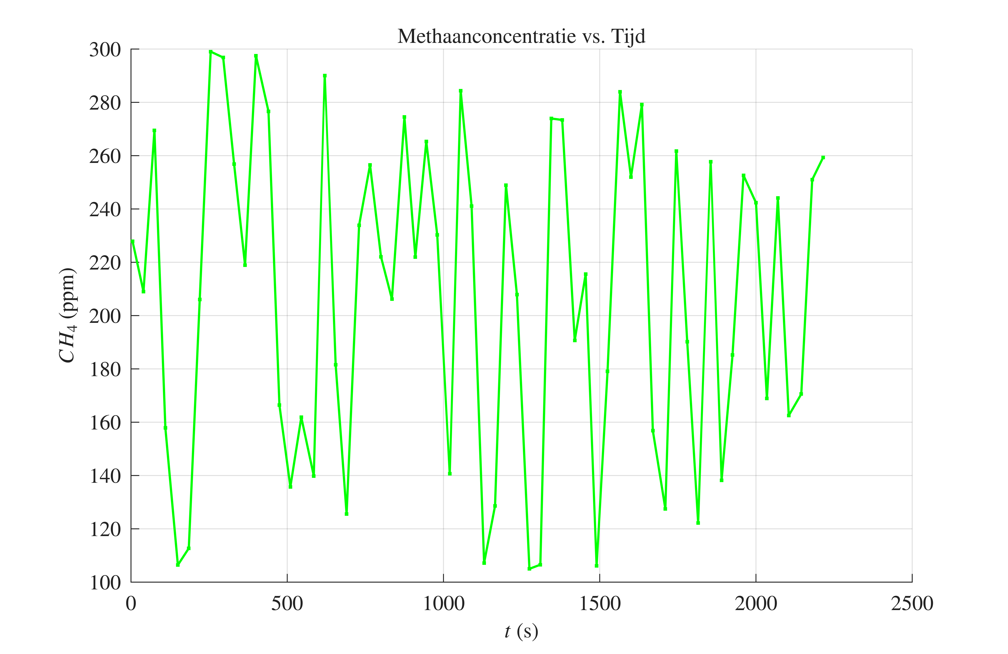
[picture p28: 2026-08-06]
assets/graphs/sensor_log_figuur_ch4.png

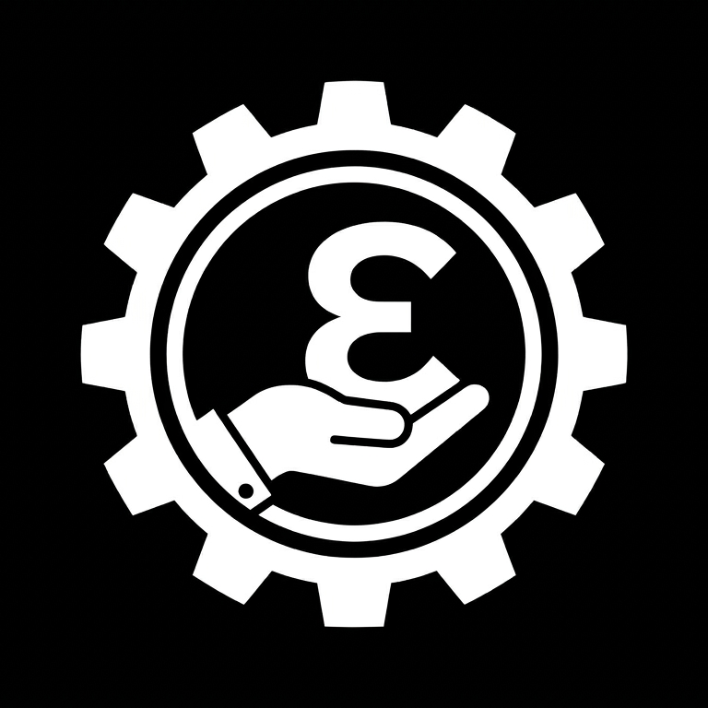
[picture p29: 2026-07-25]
assets/branding/light_with_bg.png

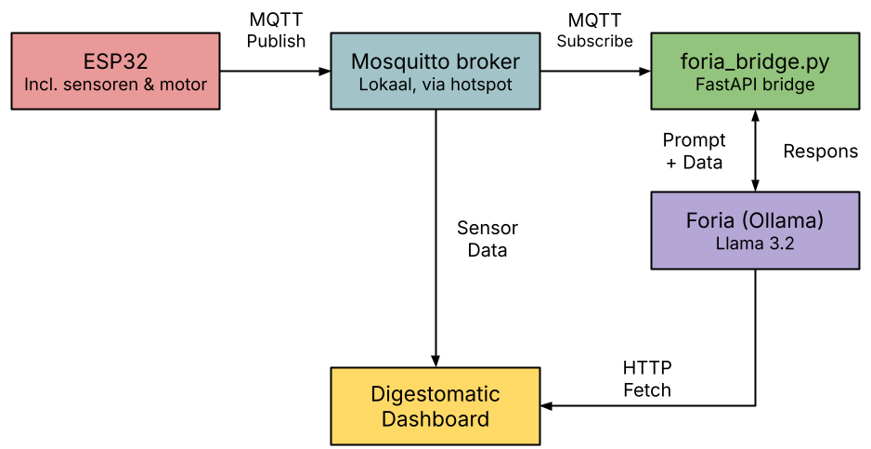
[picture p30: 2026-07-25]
assets/block diagrams/comm_arch.png

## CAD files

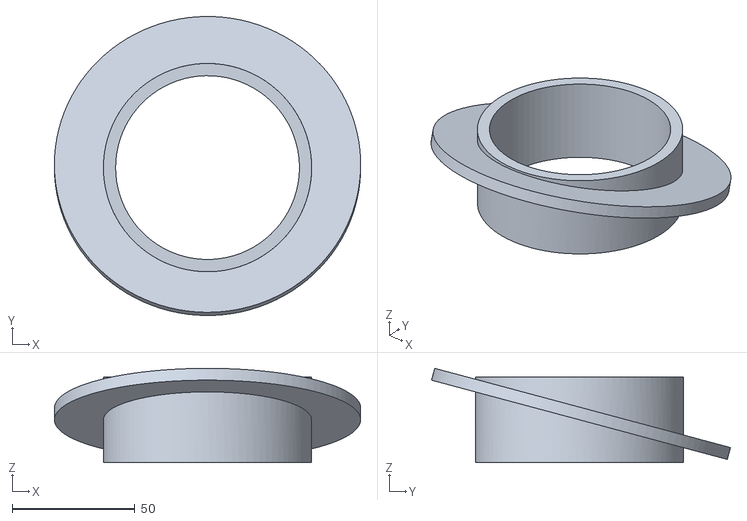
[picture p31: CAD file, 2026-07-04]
assets/3d models/Angled_Uniseal 3 Inch.stl
125.0 x 122.0 x 38.5

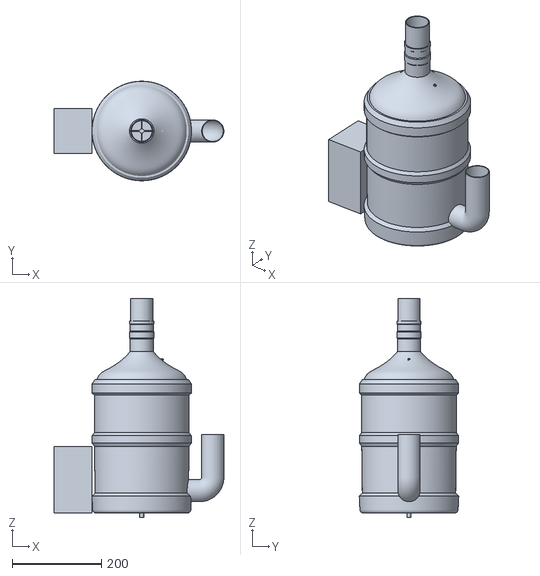
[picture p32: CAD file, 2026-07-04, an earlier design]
assets/3d models/Hackomation 3d passive digester(Old).stl
381.5 x 223.8 x 492.0

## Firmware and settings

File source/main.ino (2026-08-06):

#include <WiFi.h>
#include <ESPAsyncWebServer.h>
#include <SPIFFS.h>
#include <PubSubClient.h>

#include "customTimer.ino"
#include "dht11.ino"
#include "ds18b20.ino"
#include "dc_motor.ino"
#include "mq4.ino"
#include "mq135.ino"
#include "data_logger.ino"

// ── WiFi Config ───────────────────────────────────────────────────────────────
const char* WIFI_SSID     = "Chris' A54";
const char* WIFI_PASSWORD = "hello123";

// ── MQTT Config ───────────────────────────────────────────────────────────────
const char* MQTT_SERVER = "10.106.251.202";
const int   MQTT_PORT   = 1883;

const char* TOPIC_TEMP_OUT  = "digester/sensors/temp_outside";
const char* TOPIC_TEMP_IN   = "digester/sensors/temp_internal";
const char* TOPIC_HUM_OUT   = "digester/sensors/humidity_outside";
const char* TOPIC_METHANE   = "digester/sensors/methane";
const char* TOPIC_CO2       = "digester/sensors/co2";
const char* TOPIC_COMMANDS  = "digester/control/commands"; // e.g. "/stir" from dashboard or Foria

WiFiClient   espClient;
PubSubClient mqttClient(espClient);
AsyncWebServer server(80);

CustomTimer sensorTimer(5000); // 5-second interval

// ── MQTT ─────────────────────────────────────────────────────────────────────
void onMqttMessage(char* topic, byte* payload, unsigned int length) {
    String msg;
    for (unsigned int i = 0; i < length; i++) msg += (char)payload[i];
    msg.trim();

    Serial.print("[MQTT] ");
    Serial.print(topic);
    Serial.print(" -> ");
    Serial.println(msg);

    if (String(topic) == TOPIC_COMMANDS) {
        // Manual stir, optionally "/stir:<seconds>"
        if (msg.startsWith("/stir") || msg == "stir") {
            int colonIdx = msg.indexOf(':');
            if (colonIdx >= 0) {
                unsigned long durationSec = msg.substring(colonIdx + 1).toInt();
                if (durationSec > 0) {
                    stirrer.manualStir(durationSec);
                } else {
                    stirrer.manualStir();
                }
            } else {
                stirrer.manualStir();
            }
        }
    }
}

void reconnectMQTT() {
    while (!mqttClient.connected()) {
        Serial.print("Connecting to MQTT... ");
        String id = "ESP32Digester-" + String(random(0xffff), HEX);
        if (mqttClient.connect(id.c_str())) {
            Serial.println("connected.");
            mqttClient.subscribe(TOPIC_COMMANDS);
        } else {
            Serial.print("failed (rc=");
            Serial.print(mqttClient.state());
            Serial.println("). Retry in 5s.");
            delay(5000);
        }
    }
}

// ── Setup ─────────────────────────────────────────────────────────────────────
void setup() {
    Serial.begin(115200);
    analogReadResolution(12);
    analogSetAttenuation(ADC_11db);

    initDHT();
    initDS18B20();
    initMotor();
    initMQ4();
    initMQ135();
    initDataLogger();

    // Connect to WiFi
    WiFi.begin(WIFI_SSID, WIFI_PASSWORD);
    Serial.print("Connecting to WiFi");
    while (WiFi.status() != WL_CONNECTED) {
        delay(500);
        Serial.print(".");
    }
    Serial.println(" connected.");
    Serial.print("Dashboard: http://");
    Serial.println(WiFi.localIP());

    // SPIFFS for serving dashboard.html
    if (!SPIFFS.begin(true)) {
        Serial.println("SPIFFS mount failed.");
        return;
    }

    server.on("/", HTTP_GET, [](AsyncWebServerRequest *request) {
        request->send(SPIFFS, "/dashboard_incl_foria.html", "text/html");
    });

    server.on("/download-log", HTTP_GET, [](AsyncWebServerRequest *request) {
        if (!SPIFFS.exists(LOG_FILE_PATH)) {
            request->send(404, "text/plain", "No log data yet.");
            return;
        }
        AsyncWebServerResponse *response = request->beginResponse(
            SPIFFS, LOG_FILE_PATH, "text/csv");
        response->addHeader("Content-Disposition", "attachment; filename=\"sensor_log.csv\"");
        request->send(response);
    });

    server.serveStatic("/", SPIFFS, "/");

    server.begin();
    Serial.println("Web server started.");

    mqttClient.setServer(MQTT_SERVER, MQTT_PORT);
    mqttClient.setCallback(onMqttMessage);
}

// ── Loop ──────────────────────────────────────────────────────────────────────
void loop() {
    if (!mqttClient.connected()) reconnectMQTT();
    mqttClient.loop();

    stirrer.update(); // non-blocking — handles stir timing + independent 30-min auto-stir schedule

    if (sensorTimer.isReady()) {
        float tempOutside  = readDHT();
        float humOutside   = readDHTHumidity();
        float tempInternal = readDS18B20();
        float methanePPM   = readMQ4PPM();
        float co2PPM       = readMQ135PPM();

        Serial.print("Outside: ");  Serial.print(tempOutside,  1); Serial.print(" °C  |  ");
        Serial.print("Humidity: "); Serial.print(humOutside,   1); Serial.print(" %  |  ");
        Serial.print("Internal: "); Serial.print(tempInternal, 1); Serial.print(" °C  |  ");
        Serial.print("CH4: ");      Serial.print(methanePPM,   1); Serial.print(" ppm  |  ");
        Serial.print("CO2: ");      Serial.print(co2PPM,       1); Serial.println(" ppm");

        char buf[10];

        dtostrf(tempOutside, 1, 2, buf);
        mqttClient.publish(TOPIC_TEMP_OUT, buf);

        dtostrf(humOutside, 1, 2, buf);
        mqttClient.publish(TOPIC_HUM_OUT, buf);

        dtostrf(tempInternal, 1, 2, buf);
        mqttClient.publish(TOPIC_TEMP_IN, buf);

        if (methanePPM >= 0.0f) {
            dtostrf(methanePPM, 1, 2, buf);
            mqttClient.publish(TOPIC_METHANE, buf);
        }

        if (co2PPM >= 0.0f) {
            dtostrf(co2PPM, 1, 2, buf);
            mqttClient.publish(TOPIC_CO2, buf);
        }

        dataLogger.addRow(tempOutside, tempInternal, methanePPM, co2PPM);
    }
}

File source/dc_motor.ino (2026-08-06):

#ifndef DC_MOTOR_H
#define DC_MOTOR_H

#include <Arduino.h>

// ── Motor pins (L298N driver) ──────────────────────────────────────
#define MOTOR_ENA 25   // PWM speed control
#define MOTOR_IN1 26
#define MOTOR_IN2 27

// ── PWM config (ESP32 Arduino core v3.x API — ledcAttach/ledcWrite by pin) ─────
#define MOTOR_PWM_FREQ  1000
#define MOTOR_PWM_RES   8        // 0–255
#define MOTOR_SPEED     200      // default stir speed (0-255)

// ── Stirring behaviour ──────────────────────────────────────────────────────────
#define STIR_DURATION_MS      60000UL     // stir for 1 minute
#define AUTO_STIR_INTERVAL_MS 1800000UL   // automatic stir every 30 minutes

class DCMotor {
private:
    bool          stirring        = false;
    bool          isAutoStir      = false;         // true if the current stir was auto-triggered
    unsigned long stirStartTime   = 0;
    unsigned long stirDurationMs  = STIR_DURATION_MS; // set per-call by manualStir()/beginStir()
    unsigned long nextAutoStirAt  = 0;              // millis() timestamp of next scheduled auto-stir
    bool          autoTimerStarted = false;

    void driveForward(int speed) {
        digitalWrite(MOTOR_IN1, HIGH);
        digitalWrite(MOTOR_IN2, LOW);
        ledcWrite(MOTOR_ENA, speed);
    }

    void driveStop() {
        digitalWrite(MOTOR_IN1, LOW);
        digitalWrite(MOTOR_IN2, LOW);
        ledcWrite(MOTOR_ENA, 0);
    }

    void beginStir(const char* reason, unsigned long durationMs, bool auto_) {
        if (stirring) return; // already running, ignore re-trigger
        stirring       = true;
        isAutoStir     = auto_;
        stirDurationMs = durationMs;
        stirStartTime  = millis();
        driveForward(MOTOR_SPEED);
        Serial.print("[MOTOR] Stir started (");
        Serial.print(reason);
        Serial.print(") for ");
        Serial.print(durationMs / 1000UL);
        Serial.println("s");
    }

public:
    void begin() {
        pinMode(MOTOR_IN1, OUTPUT);
        pinMode(MOTOR_IN2, OUTPUT);
        ledcAttach(MOTOR_ENA, MOTOR_PWM_FREQ, MOTOR_PWM_RES);
        driveStop();
        nextAutoStirAt = millis() + AUTO_STIR_INTERVAL_MS;
        autoTimerStarted = true;
        Serial.println("[MOTOR] Stirrer initialized (ENA=25, IN1=26, IN2=27)");
    }

    // Handles stir duration + the independent 30-min auto-stir schedule. Manual stirs don't affect it.
    void update() {
        if (stirring && millis() - stirStartTime >= stirDurationMs) {
            stirring = false;
            driveStop();
            Serial.println("[MOTOR] Stir complete.");
        }

        if (autoTimerStarted && millis() >= nextAutoStirAt) {
            // advance schedule regardless of whether this stir actually runs
            nextAutoStirAt += AUTO_STIR_INTERVAL_MS;
            if (!stirring) {
                Serial.println("[MOTOR] Scheduled 30-min auto-stir triggered.");
                beginStir("scheduled auto-stir", STIR_DURATION_MS, true);
            } else {
                Serial.println("[MOTOR] Scheduled auto-stir skipped (motor already running).");
            }
        }
    }

    // Manual trigger (dashboard/Foria). durationSec optional. Doesn't affect the auto-stir schedule.
    void manualStir(unsigned long durationSec = STIR_DURATION_MS / 1000UL) {
        Serial.println("[MOTOR] Manual stir requested.");
        beginStir("manual request", durationSec * 1000UL, false);
    }

    bool isStirring() { return stirring; }
    bool isAutoStirring() { return stirring && isAutoStir; }
};

DCMotor stirrer;

void initMotor() {
    stirrer.begin();
}

#endif

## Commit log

2026-05-23 Add DHT11 and DS18B20 sensor support with main loop for readings
2026-05-23 .h changed to .ino for Arduino IDE compatibility. Updated main.ino to reflect these changes and removed PH sensor initialization for now.
2026-07-04 Add files via upload
    A 3d model of a 3 inch uniseal with the seal angled at 15 degrees
    [Angled_Uniseal 3 Inch.stl]
2026-07-04 Rename Angled_Uniseal 3 Inch.stl to assets/Angled_Uniseal 3 Inch.stl
    added to assets
    [Angled_Uniseal 3 Inch.stl]
2026-07-04 Add files via upload
    old 3d model of the digester.
    [Hackomation 3d passive digester(Old).stl]
2026-07-04 Rename assets/Angled_Uniseal 3 Inch.stl to assets/3D/Angled_Uniseal 3 Inch.stl
    new file for 3D models
    [Angled_Uniseal 3 Inch.stl]
2026-07-04 Rename assets/Hackomation 3d passive digester(Old).stl to assets/3D/Hackomation 3d passive digester(Old).stl
    [Hackomation 3d passive digester(Old).stl]
2026-07-04 - Added DC motor control logic in backend/dc_motor.ino to manage stirring based on methane dip detection. - Implemented MQ-4 and MQ-135 sensor readings in backend/mq4.ino and backend/mq135.ino respec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
    [Angled_Uniseal 3 Inch.stl, Hackomation 3d passive digester(Old).stl]
2026-07-05 Change load resistor value in MQ-135 configuration
2026-07-17 Enhance stirring functionality and add data logging capabilities
    - Updated DCMotor class to support customizable stir duration.
    - Modified stir endpoint in FastAPI to accept duration parameter.
    - Improved dashboard UI with timer selection for stirring.
    - Implemented DataLogger class for sensor data logging and CSV export.
2026-07-24 Add sensor and motor control modules for biodigester
    - Implement DataLogger class for logging sensor data to SPIFFS.
    - Create DCMotor class to control stirring motor with auto-stir functionality based on methane readings.
    - Add DHT11 and DS18B20 sensor modules for temperature and humidity readings.
    - Integrate MQ-4 and MQ-135 sensors for methane and CO2 concentration measurements.
    - Develop Foria bridge in Python for MQTT communication and HTTP API for dashboard interaction.
    - Create system prompt for Foria to assist users with biodigester data interpretation.
    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
    [Angled_Uniseal 3 Inch.stl, Hackomation 3d passive digester(Old).stl]
2026-07-29 Update MQTT broker and bridge host IP addresses to new configuration
    [main.ino]
2026-08-06 Removed wifi as it wasn't necessary anymore. Updated stirring logic to fix massive bug that went unnoticed. This is the final code. Thank you.
    [customTimer.ino, data_logger.ino, dc_motor.ino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]
